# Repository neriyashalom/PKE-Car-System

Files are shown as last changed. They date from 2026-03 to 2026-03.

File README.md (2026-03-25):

# PKE-Car-System

# ESP32-S3 Based PKE System for Vehicle Access and Ignition

## Project Overview
This project presents the design and implementation of a Passive Keyless Entry (PKE) system for a vehicle, based on the ESP32-S3 microcontroller.  
The system enables keyless door locking and unlocking, mirror folding and unfolding, and vehicle ignition control through a Start-Stop push button, using BLE proximity detection.

The project combines hardware, firmware, PCB design, and practical testing into a complete embedded automotive-oriented solution.  
A dedicated PCB was designed to integrate the ESP32-S3 controller, protection circuits, input conditioning stages, relay drivers, and relay blocks required for interfacing with the vehicle.

In addition to the PKE functionality, the system was designed to operate alongside the original vehicle key without interfering with its normal operation.

## System Architecture
The system is built around the following main blocks:

- ESP32-S3 controller
- BLE-based proximity detection
- Start-Stop push button interface
- Vehicle input conditioning circuits
- Protection and voltage level adaptation circuits
- Relay drivers and relay blocks
- Dedicated custom PCB
- Power management and DC-DC conversion

## Main Inputs
- BLE tag for proximity detection
- Brake pedal signal
- Handbrake signal
- Door status signal
- Ignition status signal
- Start-Stop button feedback

## Main Outputs
- Door lock control
- Door unlock control
- Mirror fold and unfold control
- ACC control
- IGN control
- START control
- Turn signal indication outputs
- Start-Stop button LED control

## Key Features
- Passive keyless vehicle access using BLE proximity detection
- Start-Stop ignition control based on defined safety conditions
- Support for vehicle functions such as mirrors, blinkers, and ignition lines
- Dedicated PCB for structured and reliable hardware integration
- State-based firmware logic for clear and predictable system behavior
- Practical implementation and testing on prototype and final PCB
- Compatibility with the original vehicle key system

## Repository Structure
- `Code/` - source code for the ESP32-S3 based PKE controller
- `KICAD/` - schematic and PCB design files created in KiCad
- `Multisim/` - simulation files used during the design and verification stages
- `ESP32S3.jpg` - image of the implemented ESP32-S3 based hardware
- `Final Project.pdf` - final project documentation and report
- `README.md` - general description of the project and repository contents

## Tools and Technologies
- **Microcontroller:** ESP32-S3
- **Firmware:** Arduino IDE, C/C++
- **PCB Design:** KiCad
- **Simulation:** Multisim
- **Communication:** BLE
- **Hardware:** Relay drivers, relays, protection circuits, DC-DC converter
- **Application Domain:** Embedded systems, automotive electronics

## Project Outcome
The project demonstrates a complete embedded hardware-software solution for implementing a custom PKE system in a vehicle environment.  
It includes concept definition, hardware design, PCB implementation, firmware development, simulation, prototype testing, and final integration.

## Author
Final project in Electrical and Electronics Engineering  
Developer: Neriya Shalom

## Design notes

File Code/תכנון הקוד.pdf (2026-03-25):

.1 דרישות תוכנה
.1.1 מטרת הפרק

פרק זה מגדיר את דרישות ההתנהגות של תוכנת הבקר עבור מערכת Entry Keyless Passive לרכב. המטרה היא לתאר בצורה ברורה את מצבי המערכת, תנאי ההפעלה, הפלטים, מגבלות הבטיחות ותרחישי הקצה, לפני תחילת כתיבת הקוד.

.1.2 הנחיות בסיסיות

- הקוד נועד לסביבת העבודה IDE Arduino.
- הקוד צריך להיות במבנה קלאסי ופשוט על ליבה אחת.
- ערכי RSSI סטנדרטיים ושינוי לפי ניסוי וטעיה.
.TARGET_MAC = "dc:0d:30:2b:84:8f" :כך | יוגדר | BLE
- סינון קלטים קטן של ms50 בנוסף לסינון החומרתי.
- טבלת הקצאת הפינים (שבשימוש) עבור הבקר ESP נמצאת בסוף המסמך.

הפרק נועד לשמש בסיס עבור:

- כתיבת לוגיקת התוכנה.
.State Machine | בניית |
- חלוקת הקוד למודולים.
- בדיקות ואימות המערכת.

.1.3 מטרת המערכת

המערכת מיועדת לאפשר:

- זיהוי משתמש באמצעות תג BLE.
- פתיחה ונעילה של הרכב.
- קיפול ופתיחת מראות.
- חיווי באמצעות וינקרים.
.ACC, IGN, START קווי | על | שליטה |
- שליטה באמצעות כפתור STOP/START חיצוני.
- עבודה במקביל למפתח המקורי של הרכב ללא התנגשות.

.1.4 קלטים למערכת

הבקר יקבל את הקלטים הבאים:

- זיהוי מפתח באמצעות BLE.
- עוצמת קליטה לצורך החלטת קרבה או התרחקות.
- SIG_BTN - פידבק מכפתור ההנעה.
- SIG_BRAKE - חיווי לחיצה על דוושת הבלם.
- SIG_HB - חיווי בלם יד משוך.
- SIG_DOOR - חיווי מצב דלתות.
- SIG_IGN - משוב מקו ההצתה לזיהוי שליטת מפתח מקורי.
- RST - איפוס חיצוני.

.1.5 פלטים מהמערכת

הבקר ישלוט בפלטים הבאים:

- LOCK - נעילת דלתות.
- UNLOCK - פתיחת דלתות.
- ACC - קו חשמל אביזרים (תאורה, רדיו).
- IGN - קו הצתה.
- START - קו התנעה.
- BLINK_R - איתות (וינקר) ימין.
- BLINK_L - איתות (וינקר) שמאל.
. | מראות | קיפול | - MIRROR_CLOSE
. | מראות | פתיחת | - MIRROR_OPEN
- LED_BTN - תאורת לד כפתור ההתנעה.

.1.6 מצבים ראשיים של המערכת

המערכת תפעל לפי המצבים העיקריים הבאים:

- IDLE - מצב אתחול ומעבר ראשוני של המערכת. הבהרה: IDLE הוא מצב אתחול ומעבר רגעי בלבד. לאחר אתחול או RST המערכת מאפסת את כל הפלטים למצב בטוח , ולאחר מכן קובעת את מצב הרכב לפי מצב ה-BLE בזמן האתחול. אם אין מפתח מזוהה, המערכת תעבור ל-LOCKED ללא הפעלת רצף נעילה נוסף. אם יש מפתח מזוהה, המערכת תבצע רצף פתיחה מלא הכולל OPEN_MIRROR ,UNLOCK ו3- הבהובי איתות, ולאחר מכן תעבור ל-IDLE .UNLOCKED אינו מצב עבודה רגיל של רכב כבוי.
- LOCKED - רכב נעול וממתין לזיהוי מפתח.

- UNLOCKED - רכב פתוח ומוכן לפעולת משתמש.
- ON_ACC - מצב אביזרים פעיל.
- ON_IGN - מצב הצתה פעיל ללא התנעה.
- CRANKING - מצב הפעלת סטרטר.
- RUNNING_ENGINE - מצב מנוע פועל.
- ACTIVE_KEY_ORIGINAL - שליטה ע"י המפתח המקורי של הרכב.

.1.7 דרישות פונקציונליות (Requirement Functional (

זיהוי קרבה:

-01FR: המערכת תזהה נוכחות משתמש באמצעות BLE.

-02FR: שינוי בין מצב "קרוב" ל"רחוק" יתבצע רק לאחר סינון תנודות בעוצמת הקליטה, כדי למנוע פתיחה או נעילה שגויה.

-03FR: שינוי מצב כתוצאה מ-RSSI יתבצע רק לאחר מעבר סף ולמשך זמן סינון שיוגדר.

פתיחה, נעילה, איתותים ומראות:

-04FR: בעת פתיחת הרכב תופעל פעולת פתיחה למשך 0.5 שנייה.

-05FR: בעת נעילת הרכב תופעל פעולת נעילה למשך 0.5 שנייה.

-06FR: בעת פתיחת הרכב יופעל חיווי וינקרים של 3 הבהובים מהירים, כאשר כל הבהוב כולל 0.333 שנייה דולק ו0.333- שנייה כבוי.

-07FR: בעת נעילת הרכב יופעל חיווי וינקרים רציף למשך 3 שניות.

-08FR: בעת פתיחת מראות יופעל פולס של 3 שניות על OPEN_MIRROR.

-09FR: בעת קיפול מראות יופעל פולס של 3 שניות על CLOSE_MIRROR.

-10FR: אם נעילה נכשלה עקב דלת פתוחה, המערכת תזהה את הכישלון מ-SIG_DOOR, תבצע פולס LOCK ולאחריו פולס UNLOCK לפי מסגרת הזמנים שהוגדרה, כדי לספק חיווי מכני לכך שהרכב לא ננעל. במקרה זה המראות לא יתקפלו כלל.

-11FR: במקרה של כישלון נעילה עקב דלת פתוחה, המערכת תפעיל 5 הבהובים מהירים בווינקרים כהתראת שגיאה כאשר כל הבהוב כולל 0.333 שנייה דולק ו0.333- שנייה כבוי.

-12FR: במקרה של כישלון נעילה, המערכת לא תאפשר התנגשות בין רצף פעיל לבין תנאי קלט חדשים, אלא תפעל לפי כללי קדימות מוגדרים. אם חל שינוי בתנאים בזמן שרצף כישלון הנעילה עדיין פעיל, הבקר יבטל את הרצף הפעיל ויעבור מיד לפעולה החדשה המתאימה. בפרט:
- אם הדלת נסגרת בזמן שה-BLE עדיין רחוק, רצף כישלון הנעילה יבוטל ותבוצע נעילה רגילה.
- אם המפתח חוזר להיות קרוב בזמן שהרצף עדיין פעיל, רצף כישלון הנעילה יבוטל ותישלח פעולת UNLOCK ליישור פיזי, והמערכת תישאר במצב UNLOCKED.
- אם לא חל שינוי בתנאים כל עוד רצף כישלון הנעילה פעיל, הבקר ישלים את שלבי הרצף הפעילים, כלומר פולס LOCK ולאחריו פולס UNLOCK, ולאחר מכן יחזור לקבל החלטות לפי מצב BLE והדלת בלולאה הראשית.

שליטת מפתח מקורי:

-13FR: אם מתקבל SIG_IGN כאשר הבקר עצמו לא הפעיל את קו IGN, המערכת תעבור למצב ACTIVE_KEY_ORIGINAL. בעת כניסה ל-ACTIVE_KEY_ORIGINAL, המערכת תבטל מיידית כל רצף PKE פעיל כולל פולסי UNLOCK/LOCK, פולסי מראות ואיתותי וינקרים.

-14FR: במצב ACTIVE_KEY_ORIGINAL הבקר יזהה שהשליטה בהנעה ובמצבי הסוויץ' מתבצעת על ידי המפתח המקורי, ולכן יעבור למצב שבו אינו מנהל את ההנעה. במצב זה הבקר יתעלם מכל פעולה שקשורה לכפתור ההנעה עד ליציאה ממצב זה, כלומר, לא יבצע פעולות START ,IGN ,ACC או כיבוי מנוע מטעמו ויכבה מיד את LED_BTN. אם בעת הכניסה למצב זה קיים הבהוב פעיל, בין אם הבהוב רגיל ובין אם הבהוב שגיאה, הכיבוי יתבצע לאחר סיום ההבהוב.

LOW | ונשאר | LOW-ל | יורד IGN_SIG | כאשר | תתבצע | ORIGINAL_KEY_ACTIVE | ממצב | היציאה | :FR-15
למשך זמן סינון קצר שיוגדר. לאחר יציאה מ-ACTIVE_KEY_ORIGINAL, הבקר לא יבצע פעולה פיזית מיידית על מנעולים, מראות או וינקרים, אלא יחזור למצב עבודה רגיל של PKE בלבד.
- BLE קרוב: המערכת תעבור ל-UNLOCKED ללא שליחת UNLOCK - ללא פתיחת מראות ואיתותים.
- BLE לא קרוב: המערכת תעבור ל-LOCKED ללא שליחת LOCK - ללא קיפול מראות ואיתותים. מכאן ואילך, כל פעולה פיזית תתבצע רק לפי לוגיקת ה-PKE הרגילה:
- BLE קרוב ובהמשך יתרחק - תתבצע נעילה רגילה או רצף כישלון נעילה לפי מצב הדלת.
- אם אין BLE בעת היציאה - לא תתבצע פעולה פיזית מיידית, מתוך הנחה שהמשתמש עשוי לעבוד רק עם המפתח המקורי ולנעול את הרכב באמצעותו.

רצף התנעה:

-16FR: התנעה תתאפשר רק כאשר המפתח מזוהה, הברקס לחוץ ובלם היד משוך.

-17FR: רצף ההתנעה בלחיצה אחת, כאשר תנאי ההתנעה מתקיימים במלואם, יהיה: הפעלת ACC ו-IGN, השהייה קצרה של שנייה אחת לצורך ייצוב המערכת ובניית לחץ דלק, ניתוק זמני של ACC, הפעלת START, ולאחר סיום START החזרת ACC.

-18FR: ההשהיה של שנייה אחת לפני START נדרשת בכל מסלול התנעה, כולל מעבר ממצב כבוי, מ-.IGN_ON-ומ ACC_ON

-19FR: מכיוון שאין במערכת משוב סל"ד (RPM(, הפעלת START תהיה מבוססת זמן. לחיצה בודדת בתנאי התנעה תקינים תפעיל את הסטרטר למשך 1.5 שניות, ולאחר מכן תנתק אותו אוטומטית.

-20FR: אם בלם היד אינו משוך, לא תתאפשר התנעה כלל, אך ACC ו -IGN עדיין יוכלו לעבוד לפי לוגיקת הכפתור.

-21FR: אם המפתח נעלם לאחר שהרכב כבר הונע, המנוע ימשיך לפעול עד לכיבוי יזום דרך הכפתור.

כפתור ההנעה וה-LED:

-22FR: ה-LED דולק ברציפות כאשר המפתח מזוהה והברקס לחוץ, או כאשר המערכת נמצאת במצב
. | הכפתור | לוגיקת | לפי ENGINE_RUNNING או ACC_ON, IGN_ON, CRANKING

-23FR: לאחר כיבוי מנוע ה-LED יכבה מיד, וגם אם הברקס עדיין לחוץ הוא יידלק מחדש רק בעקבות זיהוי מחודש של תנאי ההפעלה או לחיצה חדשה על הכפתור לפי לוגיקת המערכת.

-24FR: אם יש מפתח, בלם יד משוך וברקס לחוץ, לחיצה בודדת תגרום להתנעה. ה-LED יישאר דולק מרגע לחיצת הברקס עם הבהוב קצר לפידבק בעת הלחיצה.

-25FR: אם יש מפתח, בלם יד משוך וברקס לא לחוץ:

- לחיצה ראשונה תעביר למצב ON_ACC וה-LED יידלק.
- לחיצה שנייה תעביר למצב ON_IGN וה-LED יישאר דולק.
- לחיצה שלישית ללא ברקס, תכבה את ה-LED, תכבה ACC ו-IGN ותחזיר את המערכת ל-UNLOCKED) רכב פתוח וכבוי). אם נלחץ ברקס לפני הלחיצה השלישית, הלחיצה הבאה תגרום להתנעה.
-26FR: בכל לחיצה תקינה יתקבל הבהוב קצר של ה-LED כפידבק, מלבד לחיצה תקינה לכיבוי מנוע, שבה ה-LED עובר ממצב דולק למצב כבוי, ומעבר זה ייחשב כפידבק תקין ומספיק.

-27FR: אם אין מפתח וברקס לחוץ, ללא קשר למצב בלם היד, ה-LED יידלק בעת לחיצת הברקס. לחיצה בודדת על הכפתור תגרום ל- 4 הבהובים מהירים לציון שגיאה, ולאחר מכן ה-LED יחזור להיות דולק כל עוד הברקס לחוץ.

-28FR: אם אין מפתח וברקס לא לחוץ, ללא קשר למצב בלם היד, ה-LED יהיה כבוי, ולחיצה על הכפתור תגרום ל4- הבהובים מהירים ולאחר מכן תחזור למצב כבוי. דרישות -27FR ו-28-FR מתייחסות לכל מצב כבוי שבו אין מפתח מזוהה, כלומר כאשר המערכת אינה ב-.ENGINE_RUNNING או ACC_ON, IGN_ON

-29FR: שליטת ה-LED תתבצע דרך LED_BTN והאדמה הנשלטת על ידי 1Q.

-30FR: פידבק מהכפתור ייקרא דרך SIG_BTN.

כיבוי:

-31FR: כיבוי מנוע פועל יתאפשר רק כאשר הברקס לחוץ וגם בלם היד משוך.

-32FR: כיבוי ממצב ON_ACC או ON_IGN כאשר המנוע אינו פועל, כלומר כאשר המערכת אינה במצב RUNNING_ENGINE, יתאפשר גם ללא לחיצה על הברקס. דרישה זו תקפה גם אם המפתח היה מזוהה בעת הכניסה ל-ON_ACC או ON_IGN ולאחר מכן אבד. במקרה כזה, הלחיצה הבאה על הכפתור ממצב ON_ACC או ON_IGN תבצע כיבוי של הקווים הפעילים ותחזיר את המערכת ל-UNLOCKED, עם הבהוב קצר רגיל של ה-LED כפידבק ללחיצה תקינה ו ללא חיווי שגיאה.

-33FR: כיבוי חירום יתאפשר באמצעות לחיצה רצופה של 5 שניות על כפתור ההנעה, ללא תלות בתנאי הברקס או בלם היד.

-34FR: כאשר המנוע פועל, לחיצה קצרה על כפתור ההנעה תבצע כיבוי רק אם הברקס לחוץ וגם בלם היד משוך. אם מתקיים רק אחד התנאים, או אם אף אחד מהם אינו מתקיים, הלחיצה תתעלם ולא תבצע פעולה.

הגנה מפריקת מצבר:

-35FR: אם המערכת במצב ON_ACC או ON_IGN, המנוע אינו פועל והמפתח אינו מזוהה, המערכת תכבה אוטומטית את הקווים האלה לאחר 5 דקות.

איפוס חיצוני:

-36FR: איפוס דרך RST באמצעות כפתור חיצוני יגרום להפעלה מחדש מיידית של הבקר.

-37FR: לאחר איפוס, המערכת תחזור למצב רגיל של אתחול, קריאת מצב ה-BLE וקבלת החלטה בהתאם לנוכחות המפתח. אם בעת סיום האתחול אין מפתח מזוהה, המערכת תעבור ל-LOCKED ללא הפעלת רצף נעילה נוסף. אם בעת סיום האתחול יש מפתח מזוהה, המערכת תבצע רצף פתיחה מלא הכולל ,UNLOCK OPEN_MIRROR ו3- הבהובי איתות, ולאחר מכן תעבור ל-UNLOCKED.

.1.8 דרישות בטיחות (Requirements Safety (

-01SR: אין לאפשר התנעה ללא מפתח מזוהה.

-02SR: אין לאפשר התנעה ללא ברקס לחוץ.

-03SR: אין לאפשר התנעה ללא בלם יד משוך.

-04SR: אין לאפשר נעילה אוטומטית סופית כאשר דלת פתוחה. במקרה זה מותר לבצע רק רצף כישלון נעילה, הכולל פולס LOCK קצר ולאחריו פולס UNLOCK.

-05SR: אין לאפשר כיבוי מנוע פועל ללא ברקס לחוץ ובלם יד משוך, מלבד כיבוי חירום.

-06SR: אובדן מפתח לאחר התנעה לא יגרום לכיבוי המנוע.

-07SR: במצב ACTIVE_KEY_ORIGINAL הבקר לא ינסה להשתלט על IGN ,ACC או START.

-08SR: לאחר אתחול או איפוס, כל הפלטים יחזרו למצב בטוח כברירת מחדל.

-09SR: קווי LOCK ו-UNLOCK יופעלו כפולסים קצרים בלבד לפי הזמנים שהוגדרו.

-10SR: פולסי מראות ופולסי וינקרים יופעלו רק לפי הזמנים שהוגדרו ולא ברציפות בלתי מבוקרת.

או ACC_ON, IGN_ON, CRANKING, ENGINE_RUNNING | במצב | נמצאת | המערכת | כאשר | :SR-11
ACTIVE_KEY_ORIGINAL, מנגנון ה-PKE האוטומטי, כלומר נעילה או פתיחה מבוססת קרבה וקיפול מראות, מנוטרל לחלוטין. לא תתבצע שום פעולת מראות או מנעולים כתוצאה משינויי קליטה (RSSI (עד שהרכב יחזור למצב כבוי, כלומר LOCKED או UNLOCKED, כאשר אף קו START/IGN/ACC אינו פעיל.

-12SR: המערכת לא תפעיל במקביל פלטים או רצפים סותרים. בפרט, לא יופעלו יחד LOCK ו-UNLOCK, לא יופעלו יחד OPEN_MIRROR ו-CLOSE_MIRROR, ולא ירוץ רצף PKE אוטומטי במקביל לאירוע בעל קדימות גבוהה כגון כניסה ל-ACTIVE_KEY_ORIGINAL. במקרה של שינוי תנאים באמצע רצף פעיל, הבקר יבטל או יסיים את הרצף לפי כללי הקדימות שהוגדרו בדרישות הפונקציונליות.

.1.9 תרחישי קצה שיש לכסות

הקוד חייב להתחשב לפחות בתרחישים הבאים:

.1 לחיצה על כפתור ללא מפתח. .2 לחיצה על כפתור עם מפתח אך ללא ברקס. .3 ניסיון התנעה ללא בלם יד. .4 ניסיון נעילה כאשר דלת פתוחה. .5 אובדן מפתח לאחר התנעה.
.6 כיבוי חירום בלחיצה ארוכה.

.7 איפוס בזמן שהמערכת ב-IGN ,ACC או RUNNING_ENGINE. .8 שליטת מפתח מקורי דרך SIG_IGN. .9 מעבר חזרה מ-ACTIVE_KEY_ORIGINAL למצב רגיל. .10 תנודות RSSI הגורמות לזיהוי קרבה לא יציב. .11 ניסיון כיבוי מנוע פועל ללא ברקס ובלם יד. .12 כישלון נעילה והפעלת פתיחה מחדש. .13 מעבר מהיר ממצב כבוי להתנעה בלחיצה אחת תוך התחשבות בהשהייה של שנייה אחת לפני START. .14 התנעה לאחר שהמשתמש כבר העלה את המערכת ל-IGN בלחיצות קודמות, גם במעבר מ-ON_IGN ישירות להתנעה, השהיית DELAY_START_PRE תמיד מתקיימת, ואין מסלול התנעה ללא השהיה . .15 שחרור ברקס באמצע ניסיון התנעה. .16 שינוי תנאים באמצע רצף כישלון נעילה:
- אם הדלת נסגרת בזמן שרצף כישלון הנעילה עדיין פעיל וה-BLE עדיין רחוק, המערכת תבטל את הרצף הפעיל ותבצע נעילה רגילה מיד.
- אם המפתח חוזר להיות קרוב בזמן שרצף כישלון הנעילה עדיין פעיל, המערכת תבטל את הרצף הפעיל, תשלח UNLOCK ליישור פיזי, ותישאר במצב UNLOCKED.

.1.10 ערכי זמן קבועים

המערכת תתבסס על הערכים הבאים:

LOCK_PULSE = 0.5s
זמן הפעלת פלט הנעילה.
UNLOCK_PULSE = 0.5s
זמן הפעלת פלט הפתיחה.
LOCK_BLINK_DURATION = 3s זמן הפעלת שני צדדי הווינקר בנעילה. UNLOCK_BLINK_COUNT = 3
בפתיחה שני צדדי הווינקר יבוצעו 3 הבהובים. UNLOCK_BLINK_ON_TIME = 0.333s משך הזמן שבו הווינקרים דולקים בכל הבהוב פתיחה. UNLOCK_BLINK_OFF_TIME = 0.333s משך הזמן שבו הווינקרים כבויים בין הבהובי הפתיחה. LOCK_FAIL_BLINK_COUNT = 5 במקרה של כישלון נעילה יבוצעו 5 הבהובים של הווינקרים. LOCK_FAIL_BLINK_ON_TIME = 0.333s משך הזמן שבו הווינקרים דולקים בכל הבהוב של כישלון נעילה. LOCK_FAIL_BLINK_OFF_TIME = 0.333s משך הזמן שבו הווינקרים כבויים בין הבהובי כישלון הנעילה. LED_BLINK_ON_TIME = 0.333s משך הזמן שבו הלד דולק בכל הבהוב של מעבר מצב בלחיצות.

LED_BLINK_OFF_TIME = 0.333s משך הזמן שבו הלד כבוי בכל הבהוב של מעבר מצב בלחיצות. LED_ERROR_BLINK_COUNT = 4 במקרה של שגיאה או פקודת התנעה לא חוקית יבוצעו 4 הבהובים של הלד. LED_ERROR_BLINK_ON_TIME = 0.333s משך הזמן שבו הלד דולק בכל הבהוב של שגיאה או פקודת התנעה לא חוקית. LED_ERROR_BLINK_OFF_TIME = 0.333s משך הזמן שבו הלד כבוי בין הבהובי שגיאה או פקודת התנעה לא חוקית. MIRROR_OPEN_PULSE = 3s
זמן הפעלת פלט פתיחת המראות. MIRROR_CLOSE_PULSE = 3s
זמן הפעלת פלט קיפול המראות. PRE_START_DELAY = 1s
השהיה לייצוב המערכת ובניית לחץ דלק לפני הפעלת הסטרטר. START_PULSE = 1.5s
זמן הפעלת הסטרטר.
EMERGENCY_STOP_PRESS = 5s משך לחיצה רצופה על כפתור ההנעה לצורך כיבוי חירום. ACC_IGN_AUTO_OFF_TIMEOUT = 5min זמן מקסימלי למצב ACC או IGN ללא מנוע פועל וללא מפתח מזוהה.

.1.11 מבנה תוכנה

התוכנה תחולק למודולים נפרדים:
- קריאת קלטים.
- סינון קלטים .
- BLE וזיהוי קרבה.
- טיימרים.
.State Machine
- לוגיקת כפתור ההנעה.
- לוגיקת התנעה וכיבוי.
- לוגיקת נעילה, פתיחה, מראות ואיתותים.
.ORIGINAL_KEY_ACTIVE | במצב | טיפול |
- טיפול בתקלות ובמצבי חסימה.

.1.12 דרישות תוכנה (Requirement Software (

-01SW: כל לוגיקת ההחלטה תתבצע דרך Machine State מסודר.

-02SW: כל קלט חיצוני יעבור סינון לפני שימוש בלוגיקה הראשית.

-03SW: כל פלט בזמן ריצת המערכת יופעל דרך פונקציה ייעודית אחת בלבד.

-04SW: ניהול רצפים אסינכרוניים יתבצע באמצעות דגלי מצב, טיימרים וכללי קדימות ברורים, כך שבכל רגע נתון לכל תחום פעולה יהיה רצף פעיל אחד בלבד.

-05SW: בעת שינוי תנאים במהלך רצף פעיל, ההחלטה אם לבטל את הרצף או לאפשר לו להסתיים תיקבע לפי כללי הקדימות שהוגדרו בדרישות הפונקציונליות והבטיחות.

הקצאת הפינים (שבשימוש) עבור הבקר ESP מפורטת בטבלה הבאה:

תיאור | I/O Type | GPIO | Signal Name
מוצא V3.3 המשמש כמתח יחוס לכניסות חיווי DOOR_NEG-ו HB_NEG | - 3V3 Power Output
(Reset) חומרתי איפוס לחצן | Input | EN | RST
| | | LOCK 4 Output מוצא לדרייבר ממסר נעילת דלתות הרכב
| | | UNLOCK 9 Output מוצא לדרייבר ממסר פתיחת דלתות הרכב
כניסת חיווי דוושת בלם (משוחרר/משוך) לאחר הגבלת מתח הכניסה | | | SIG_BRAKE 10 Input
| | | SIG_HB 11 Input כניסת חיווי בלם יד לאחר הגבלת מתח הכניסה
כניסת חיווי מצב דלתות הרכב (פתוחות/סגורות) לאחר הגבלת מתח הכניסה | | | SIG_DOOR 12 Input
כניסת חיווי מצב הצתה מהרכב ע"י מפתח מקורי לצורך השבתת המערכת לאחר הגבלת מתח הכניסה | Input | 13 | IGN_SIG
כניסת חיווי מכפתור ההנעה לאחר הגבלת מתח הכניסה | | | SIG_BTN 14 Input
| | | V+5 - Input Power כניסת מתח V5 מממיר המתח
| | | GND - Power חיבור אדמה משותף למרכב הרכב
| | | GND - Power חיבור אדמה משותף למרכב הרכב
| | | START 1 Output מוצא לדרייבר ממסר הפעלת הסטרטר (התנעה)
מוצא לדרייבר ממסר הפעלת מתח אביזרים (תאורה, מצת וכד') | | | ACC 2 Output
| | | IGN 42 Output מוצא לדרייבר ממסר הפעלת מערכת ההצתה
| | | CLOSE_MIRROR 41 Output מוצא לדרייבר ממסר סגירת מראות הצד
| | | OPEN_MIRROR 40 Output מוצא לדרייבר ממסר פתיחת מראות הצד
| | | BLINK_L 48 Output מוצא לדרייבר ממסר הפעלת איתות שמאלי
| | | BLINK_R 47 Output מוצא לדרייבר ממסר הפעלת איתות ימני
מוצא לדרייבר ממסר הפעלת תאורה בכפתור ההנעה | | | LED_BTN 21 Output
| | | GND - Power חיבור אדמה משותף למרכב הרכב
| | | GND - Power חיבור אדמה משותף למרכב הרכב

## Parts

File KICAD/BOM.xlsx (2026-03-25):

Reference | Footprint | Qty | Perfboard (ללוח הלחמה לבדיקה) | SMD (ללוח PCB מודפס)
C1,C3,C4,C5,C6,C7 | Capacitor_SMD:C_0805_2012Metric_Pad1.18x1.45mm_HandSolder | 6 | 100n THT | Capacitor 100nF 50V X7R 0805
C2 | Capacitor_THT:CP_Radial_D8.0mm_P3.50mm | 1 | 50V220u THT | Electrolytic Capacitor 220uF 50V Radial_D8.0mm_P3.50mm
D1 | Diode_SMD:D_SMB_Handsoldering | 1 | SR560 THT | SS56 SMB
D2 | Diode_SMD:D_SMC_Handsoldering | 1 | P6KE18A THT | SMCJ18A SMC
D3,D5,D6,D7,D8 | Diode_SMD:D_SOD-123 | 5 | 1N4728A THT | BZT52C3V3 SOD-123
D4,D9,D10,D11,D12,D13,D14,D15,D16,D17 | Diode_SMD:D_SMA_Handsoldering | 10 | 1N4007 THT | 1N4007 SMA
ESP32_S3_DevKitC_1 | ESP32-S3-DevKitC-1-N32R16V:ESP32S3DevKitC1N32R16V | 1 | ESP32_S3_DevKitC THT | ESP32_S3_DevKitC THT
F1 | Fuse:Fuse_1812_4532Metric_Pad1.30x3.40mm_HandSolder | 1 | FUSE_DCDC 1.1A THT | 1812 4.8*3.2mm
F2 | Fuse:Fuse_1812_4532Metric_Pad1.30x3.40mm_HandSolder | 1 | FUSE_COILS 1.1A THT | 1812 4.8*3.2mm
J1,J3 | Connector_Molex:Molex_Mini-Fit_Jr_5569-06A2_2x03_P4.20mm_Horizontal | 2 | Molex_Mini-Fit_Jr_5569-06A2_2x03 THT | Molex_Mini-Fit_Jr_5569-06A2_2x03 THT
J2 | Connector_Molex:Molex_Mini-Fit_Jr_5569-16A2_2x08_P4.20mm_Horizontal | 1 | Molex_Mini-Fit_Jr_5569-16A2_2x08 THT | Molex_Mini-Fit_Jr_5569-16A2_2x08 THT
J_DCDC1 | Connector_PinHeader_2.54mm:PinHeader_1x03_P2.54mm_Vertical | 1 | 3 Holes for external module THT | 3 Holes for external module THT
J_RST1 | Connector_PinHeader_2.54mm:PinHeader_1x02_P2.54mm_Horizontal | 1 | 2 Holes for external module THT | 2 Holes for external module THT
K1,K2,K3,K4,K5,K6,K7,K8,K9 | CMA51H_RELAY:CMA51HSDC12VC | 9 | CMA51H-S-DC12V-C THT | CMA51H-S-DC12V-C THT
Q1,Q2,Q3,Q4,Q5,Q6,Q7,Q8,Q9,Q10 | Package_TO_SOT_SMD:SOT-23-3 | 10 | 2N2222A THT | MMBT2222A SOT-23-3
R1,R2,R7,R10,R13,R16,R18,R19,R20,R24,R25,R28,R29,R32,R33 | Resistor_SMD:R_0805_2012Metric_Pad1.20x1.40mm_HandSolder | 15 | 1k THT | Resistor 1k 0805
R3,R6,R15 | Resistor_SMD:R_0805_2012Metric_Pad1.20x1.40mm_HandSolder | 3 | 30k THT | Resistor 30k 0805
R4,R21,R22,R23,R26,R27,R30,R31,R34,R35 | Resistor_SMD:R_0805_2012Metric_Pad1.20x1.40mm_HandSolder | 10 | 100k THT | Resistor 100k 0805
R5,R8,R17 | Resistor_SMD:R_0805_2012Metric_Pad1.20x1.40mm_HandSolder | 3 | 10k THT | Resistor 10k 0805
R9,R12 | Resistor_SMD:R_0805_2012Metric_Pad1.20x1.40mm_HandSolder | 2 | 4.7k THT | Resistor 4.7k 0805
R11,R14 | Resistor_SMD:R_0805_2012Metric_Pad1.20x1.40mm_HandSolder | 2 | 47k THT | Resistor 47k 0805

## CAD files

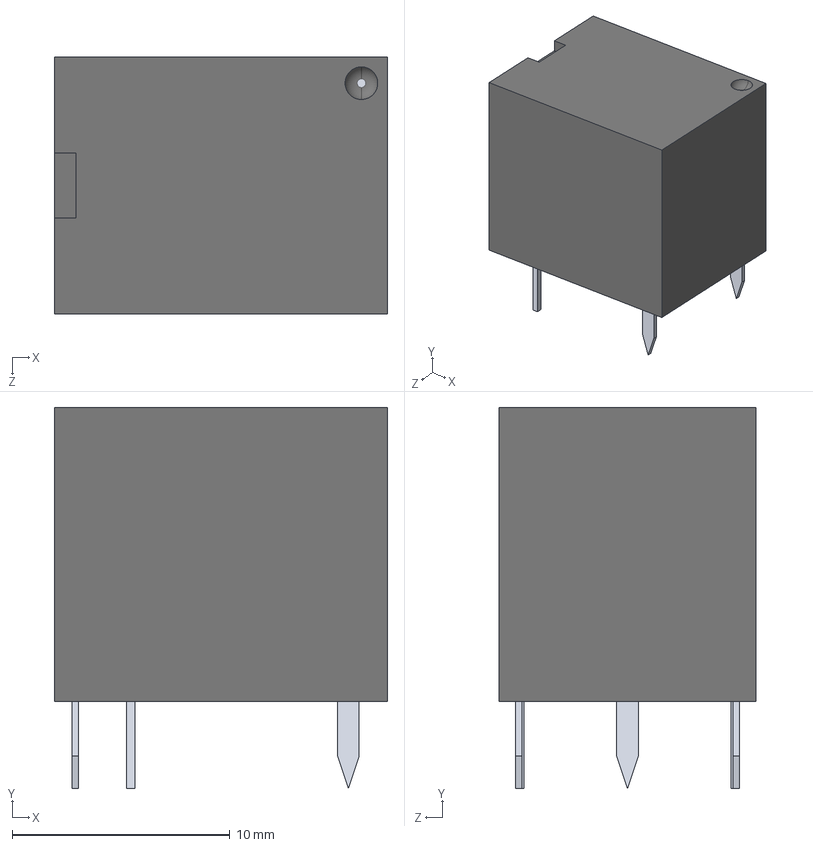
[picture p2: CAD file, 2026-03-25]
KICAD/CMA51H_RELAY/CMA51H-S_DC12V-C_20A.STEP
15.3 x 17.5 x 11.8 mm

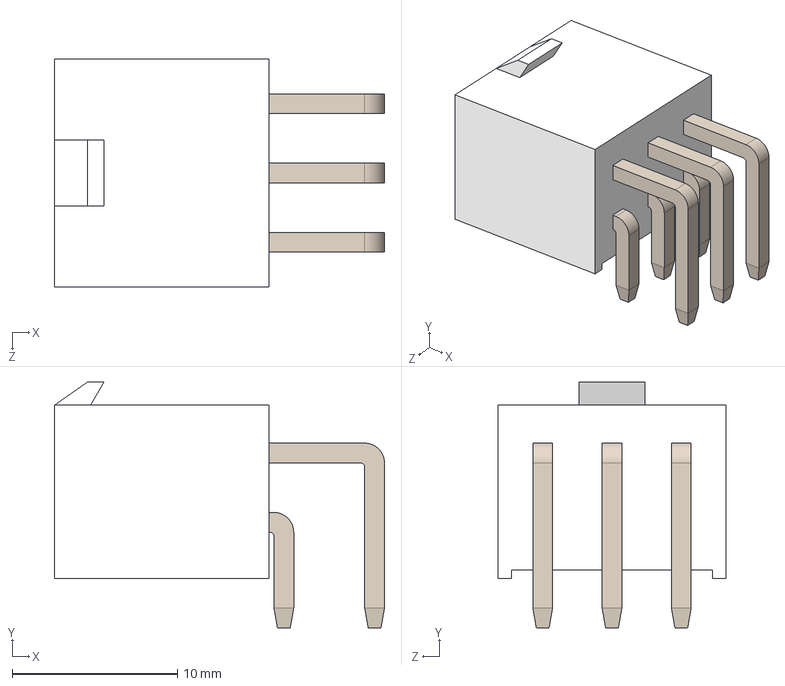
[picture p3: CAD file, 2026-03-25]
KICAD/Connectors/5557-2x1aw-5557-2x2aw-5557-2x3aw-5557-2x4aw-5557-2x5aw-1.snapshot.3/5557 2x3AW.STEP
20.0 x 14.9 x 13.8 mm

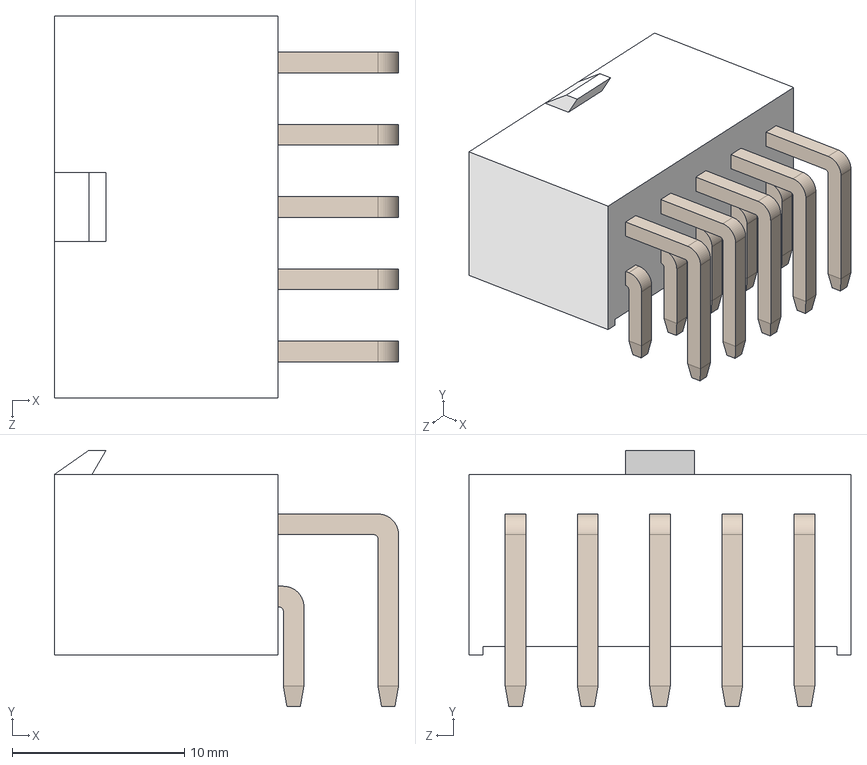
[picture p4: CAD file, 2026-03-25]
KICAD/Connectors/5557-2x1aw-5557-2x2aw-5557-2x3aw-5557-2x4aw-5557-2x5aw-1.snapshot.3/5557 2x5AW.STEP
20.0 x 14.9 x 22.2 mm

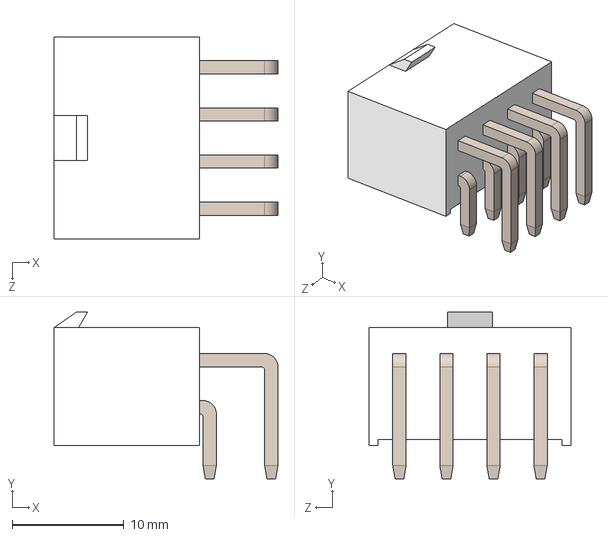
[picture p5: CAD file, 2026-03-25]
KICAD/Connectors/5557-2x1aw-5557-2x2aw-5557-2x3aw-5557-2x4aw-5557-2x5aw-1.snapshot.3/5557 2x4AW.STEP
20.0 x 14.9 x 18.0 mm

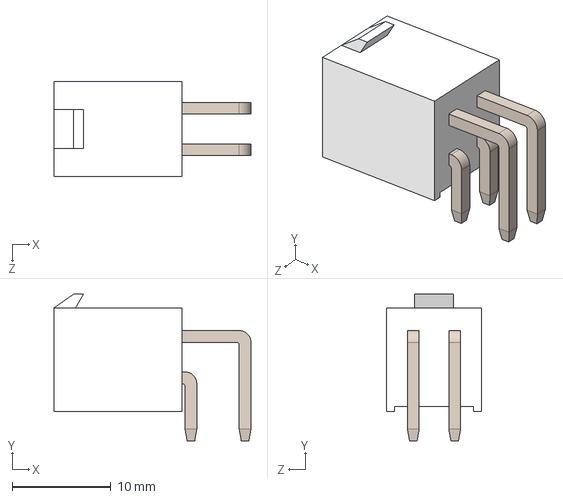
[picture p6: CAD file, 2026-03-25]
KICAD/Connectors/5557-2x1aw-5557-2x2aw-5557-2x3aw-5557-2x4aw-5557-2x5aw-1.snapshot.3/5557 2x2AW.STEP
20.0 x 14.9 x 9.60 mm

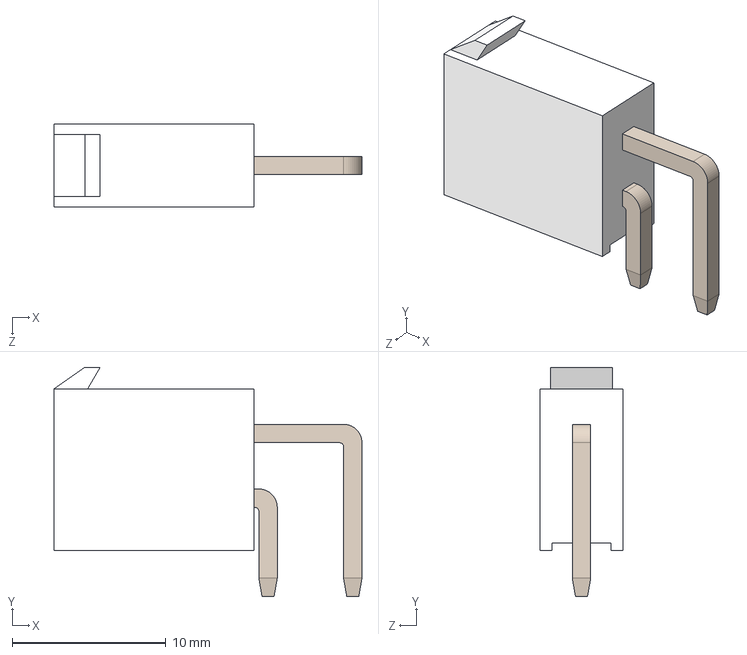
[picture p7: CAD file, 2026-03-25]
KICAD/Connectors/5557-2x1aw-5557-2x2aw-5557-2x3aw-5557-2x4aw-5557-2x5aw-1.snapshot.3/5557 2x1AW.STEP
20.0 x 14.9 x 5.40 mm

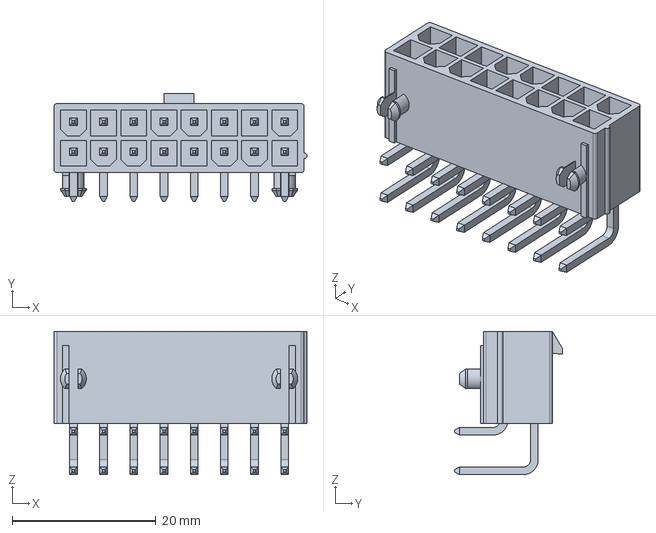
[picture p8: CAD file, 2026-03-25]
KICAD/Connectors/Molex_Mini-Fit_Jr_5569-16A2/0039301160.stp
35.2 x 15.0 x 19.9 mm

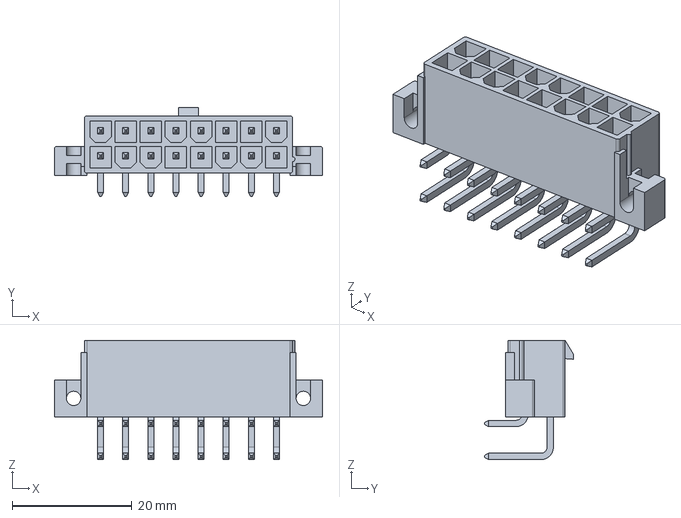
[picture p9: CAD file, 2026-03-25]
KICAD/Connectors/Molex_Mini-Fit_Jr_5569-16A2/0039291168.stp
44.8 x 14.9 x 19.9 mm

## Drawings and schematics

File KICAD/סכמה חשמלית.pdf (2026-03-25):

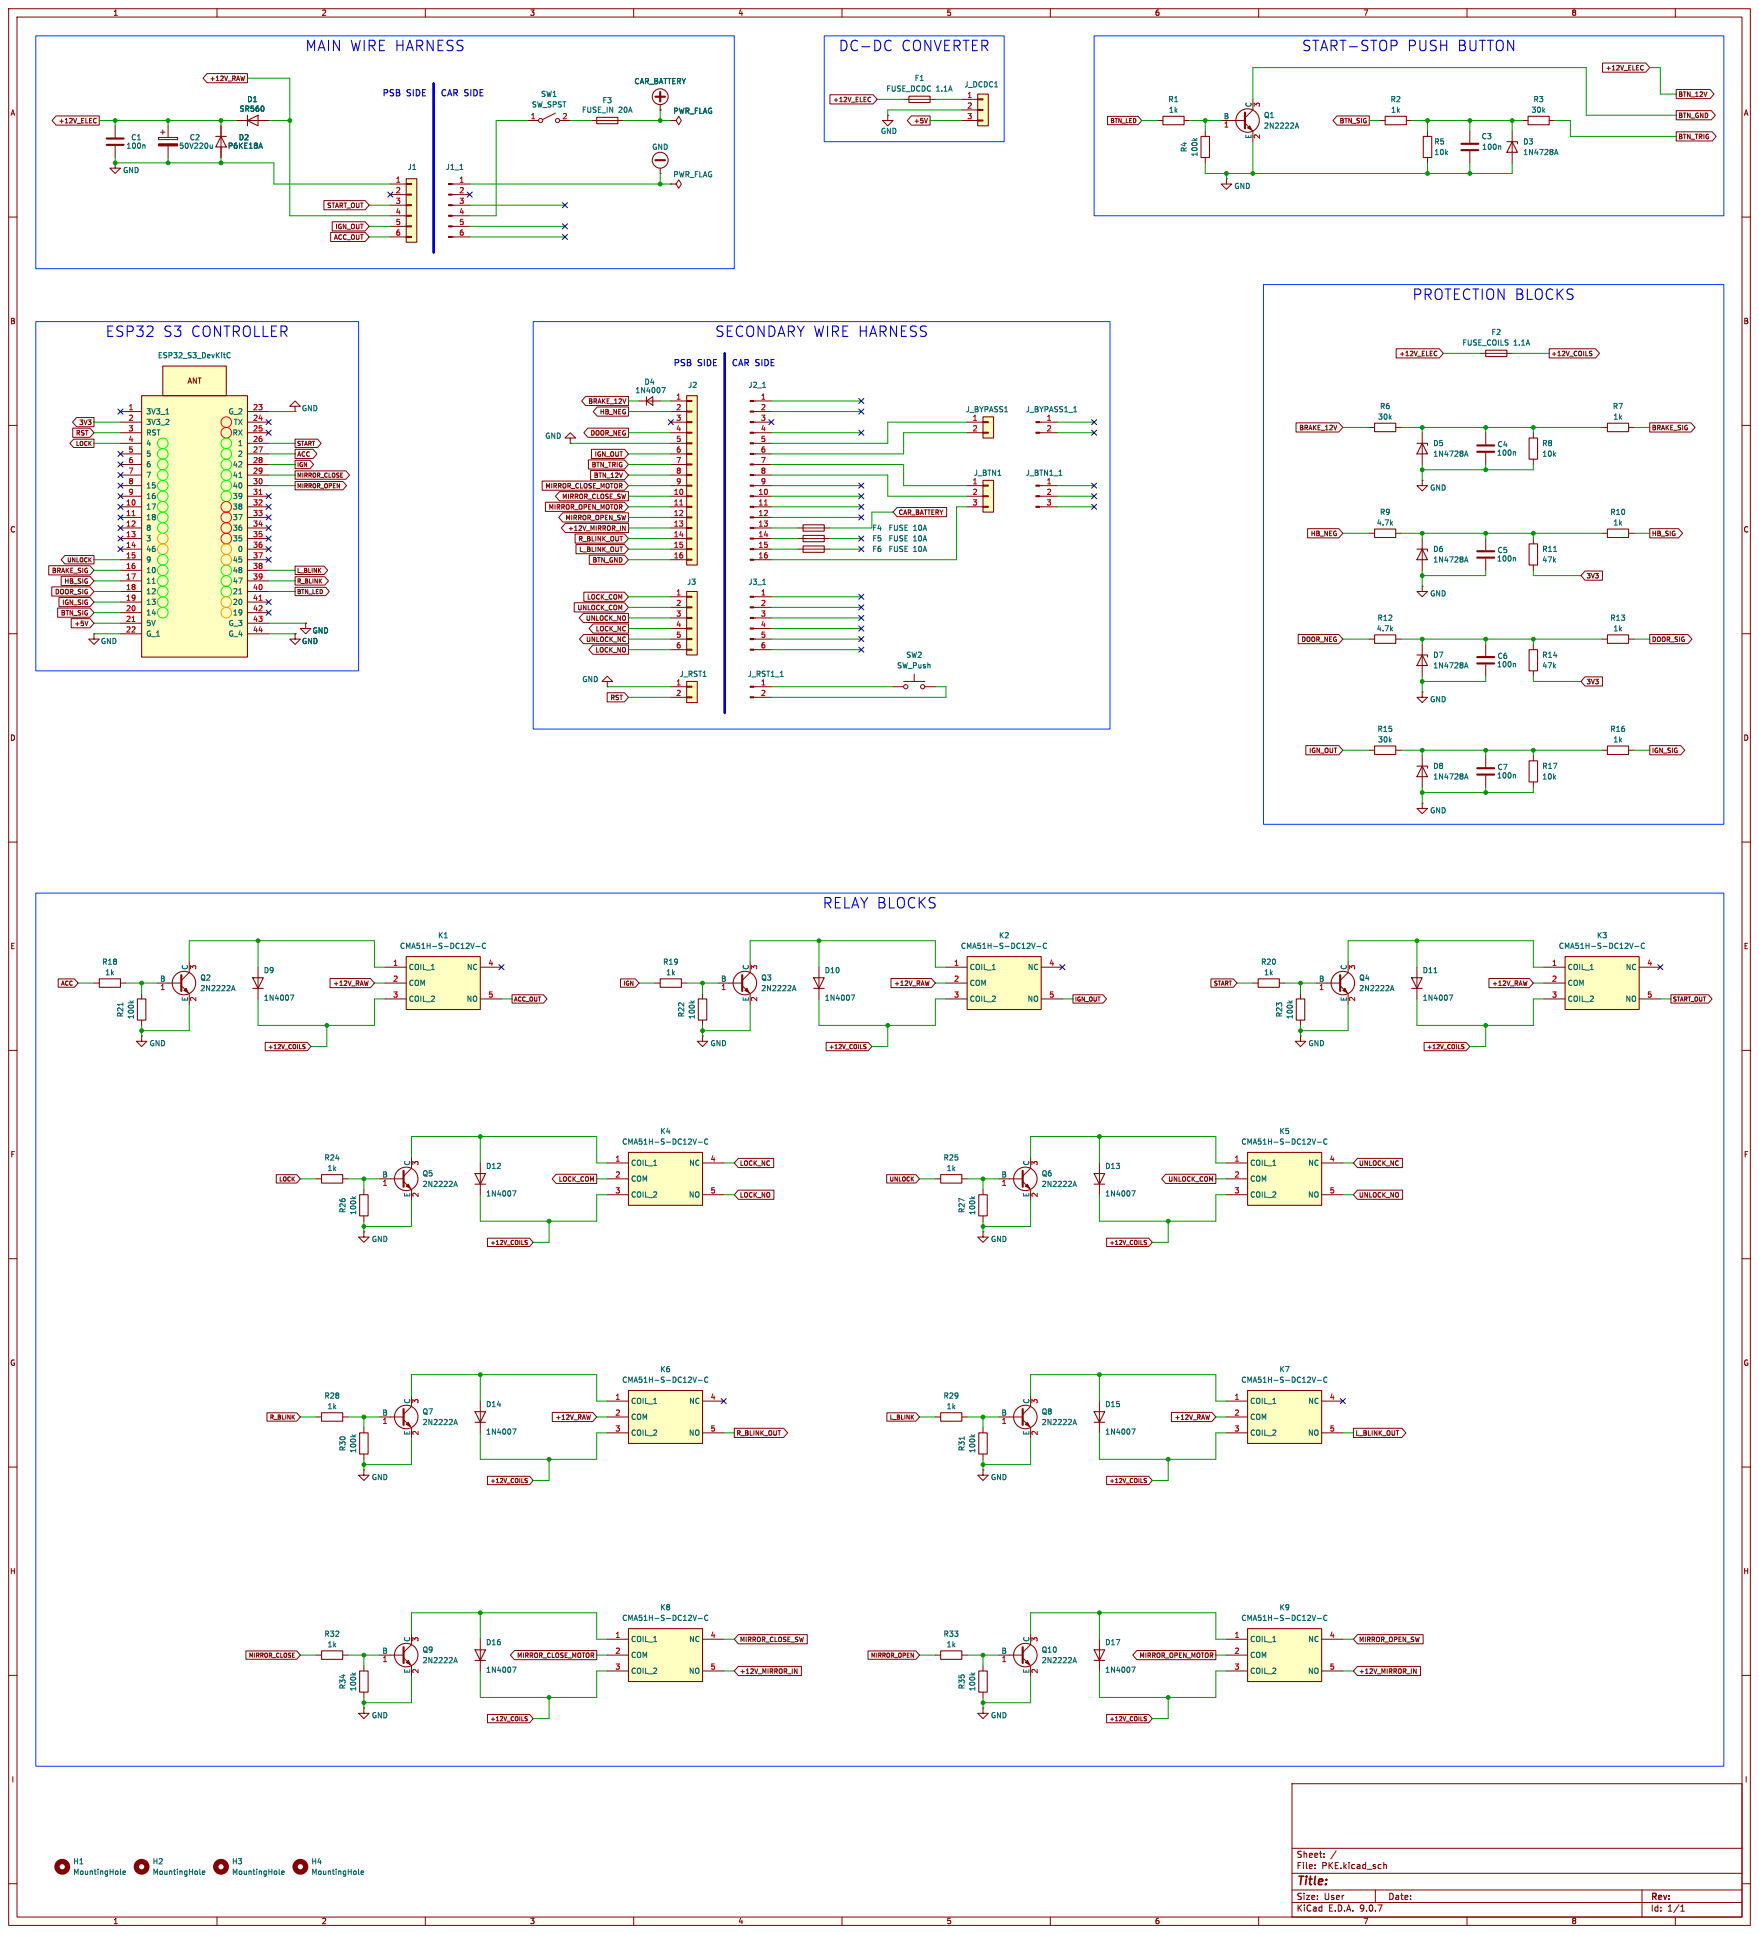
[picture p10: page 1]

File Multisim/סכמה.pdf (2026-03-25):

## D(freq): --

## D(freq): --

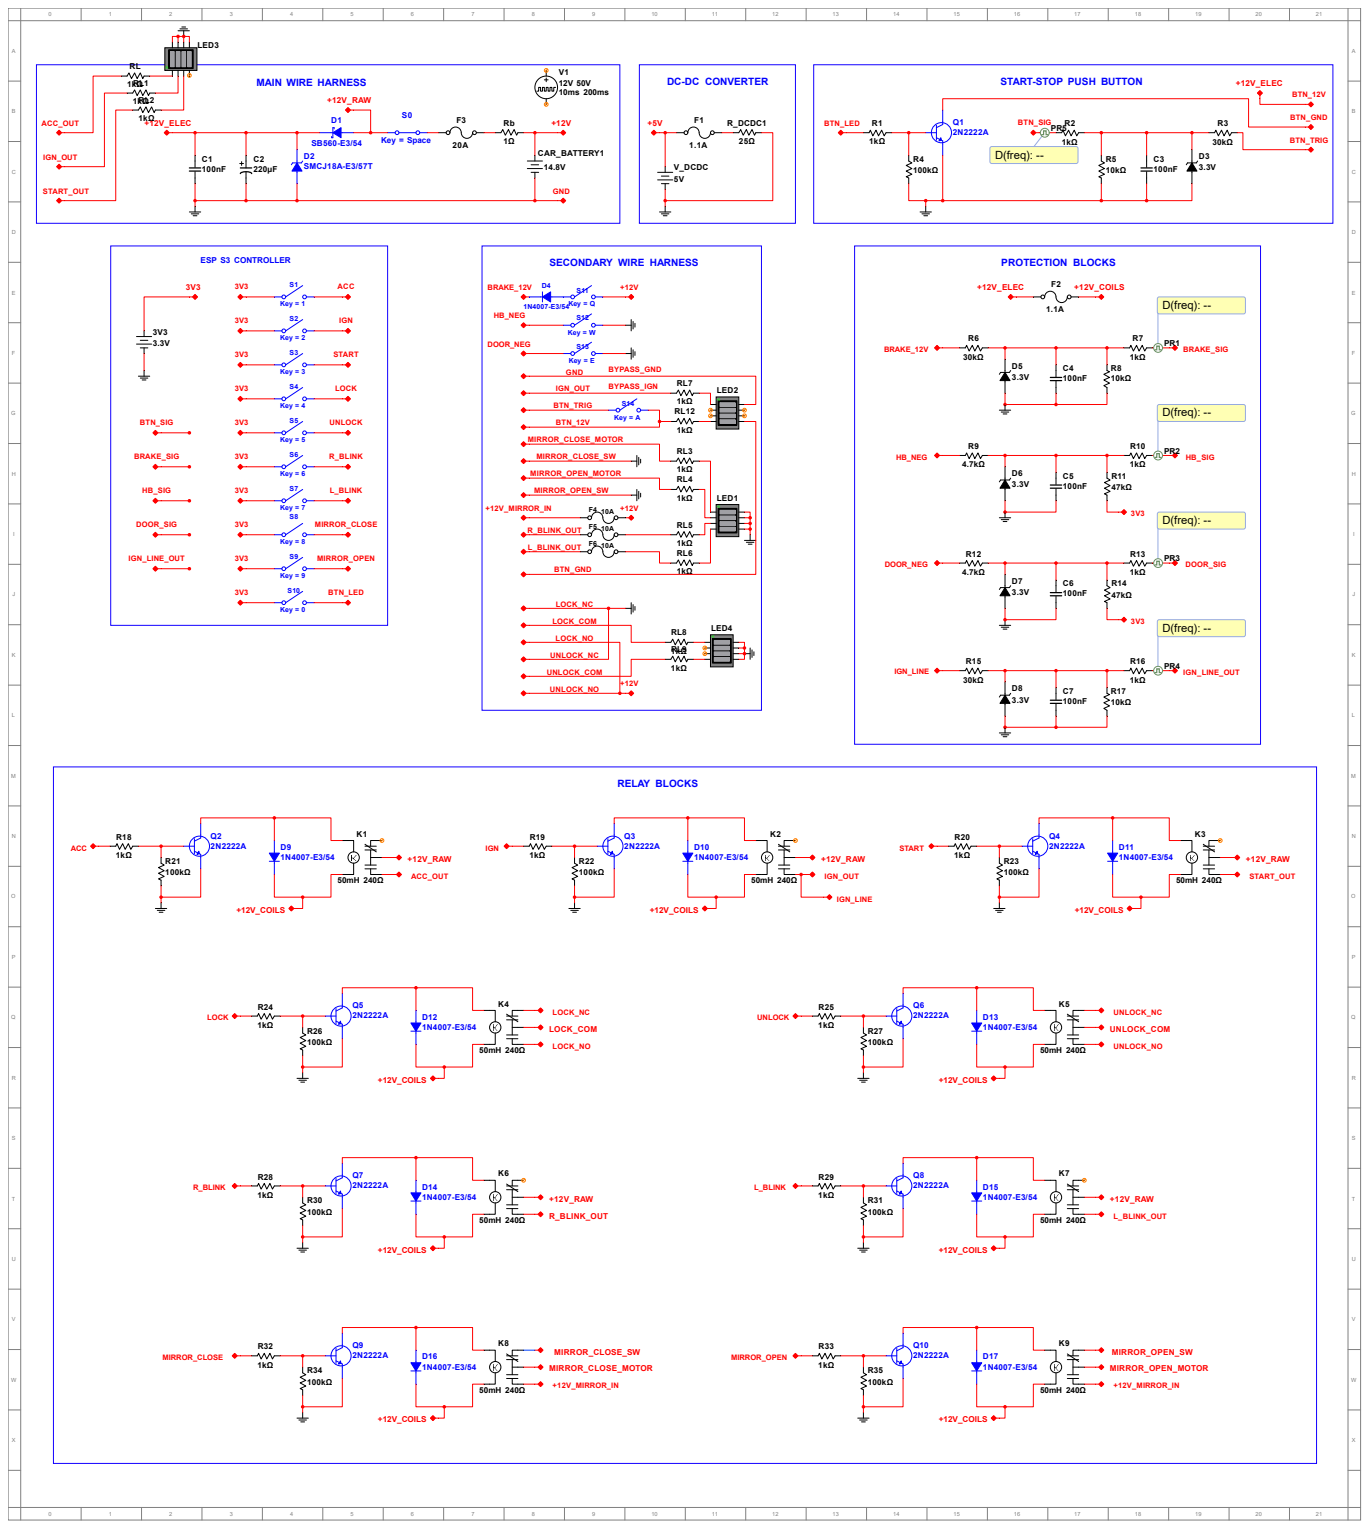
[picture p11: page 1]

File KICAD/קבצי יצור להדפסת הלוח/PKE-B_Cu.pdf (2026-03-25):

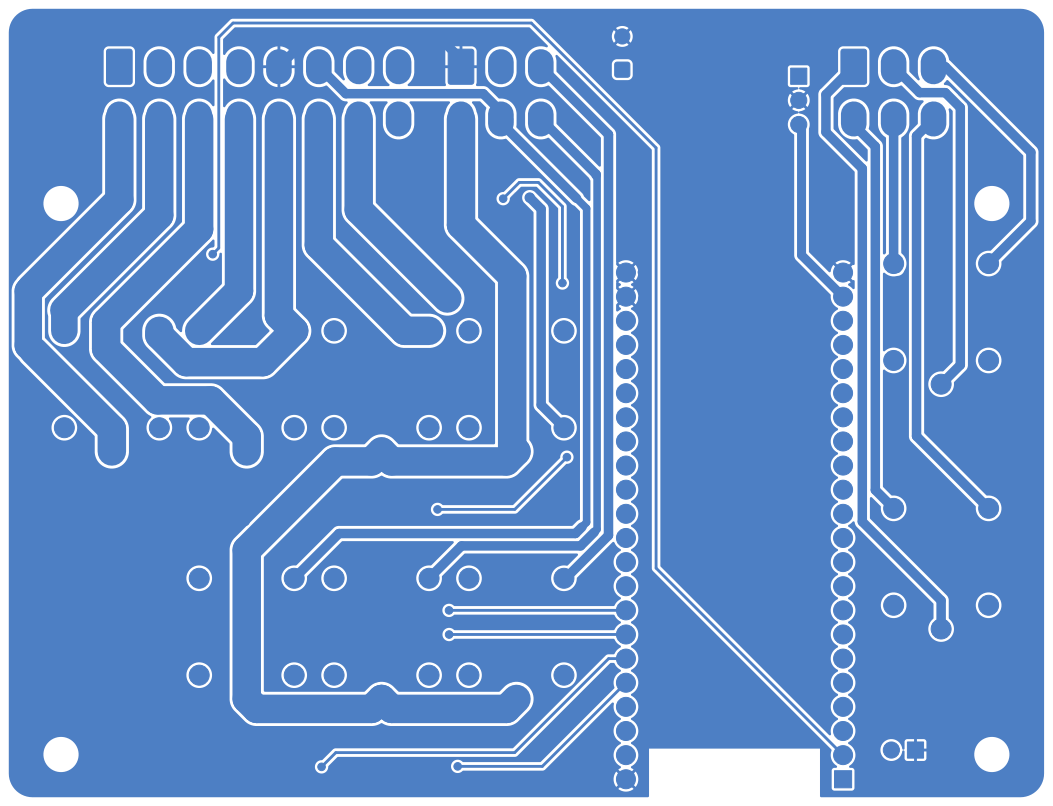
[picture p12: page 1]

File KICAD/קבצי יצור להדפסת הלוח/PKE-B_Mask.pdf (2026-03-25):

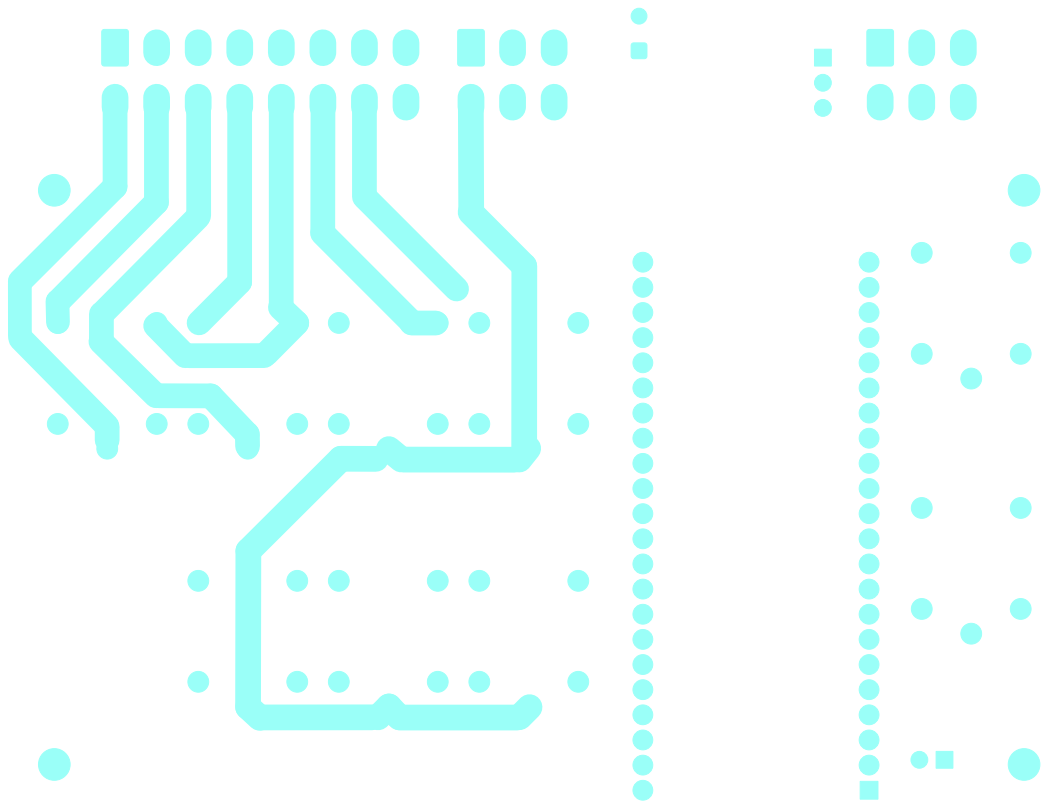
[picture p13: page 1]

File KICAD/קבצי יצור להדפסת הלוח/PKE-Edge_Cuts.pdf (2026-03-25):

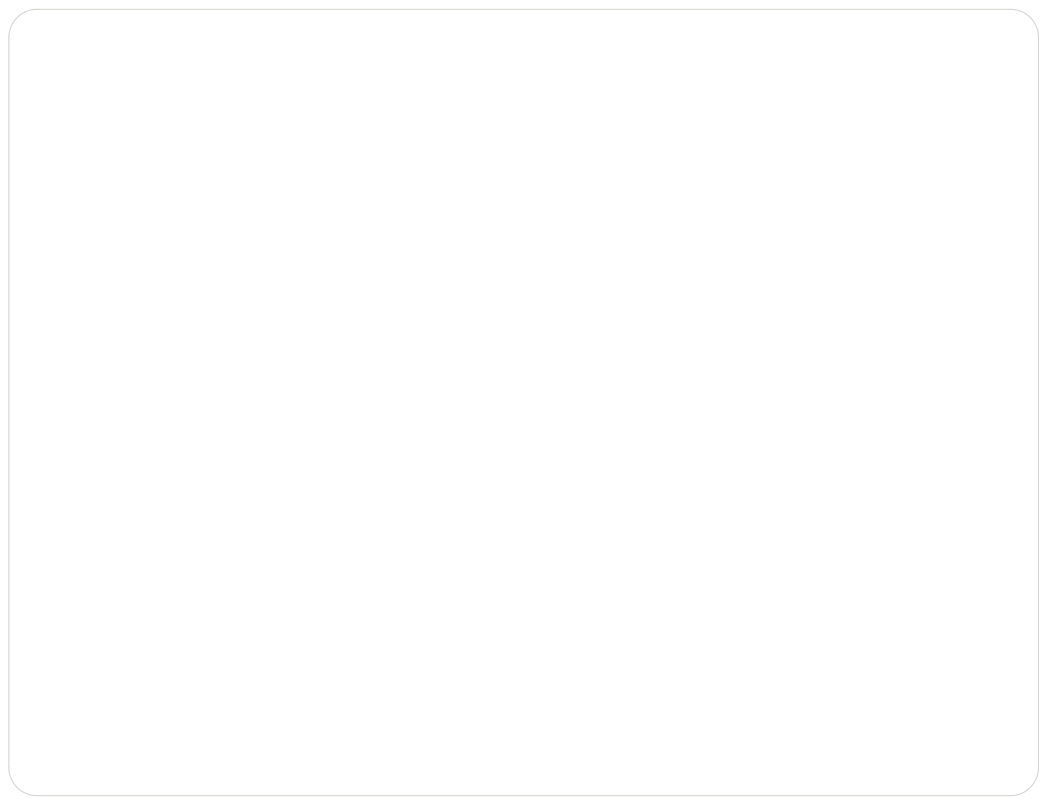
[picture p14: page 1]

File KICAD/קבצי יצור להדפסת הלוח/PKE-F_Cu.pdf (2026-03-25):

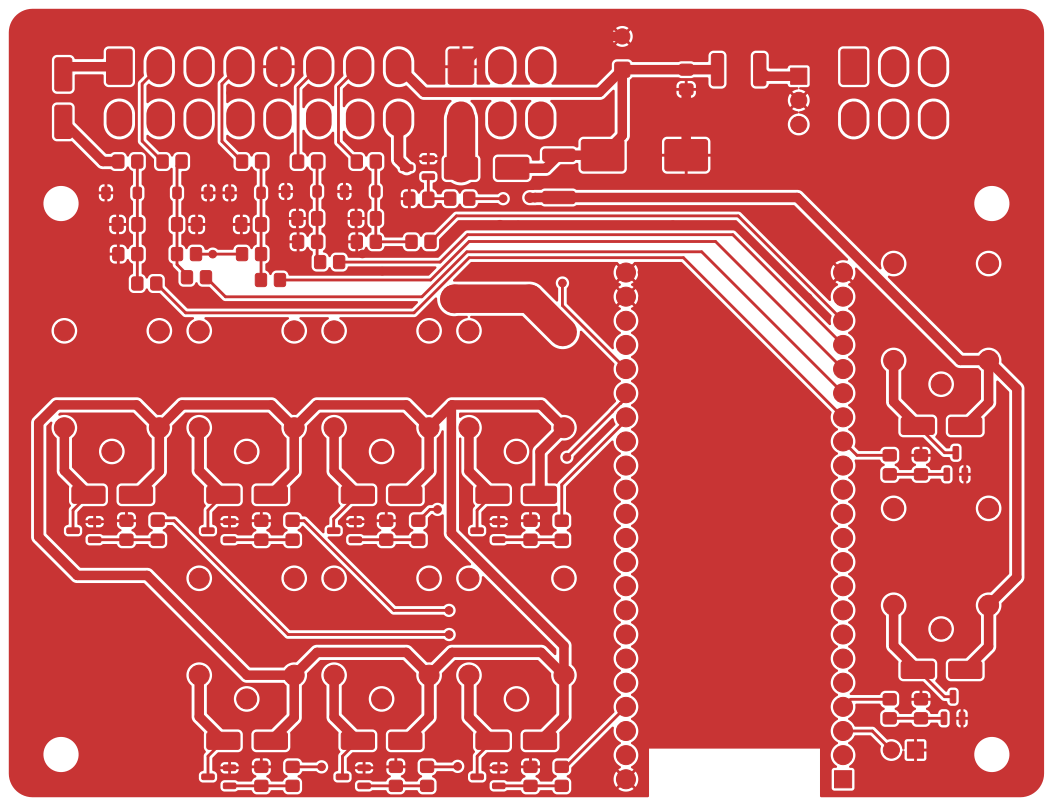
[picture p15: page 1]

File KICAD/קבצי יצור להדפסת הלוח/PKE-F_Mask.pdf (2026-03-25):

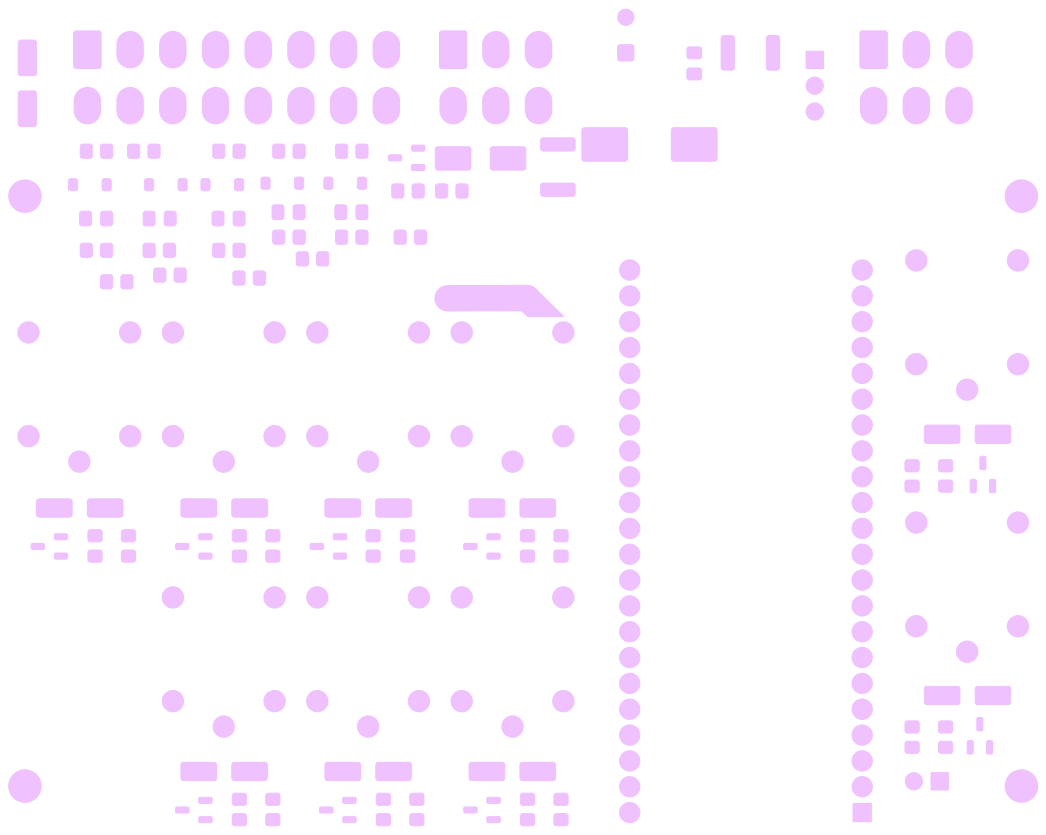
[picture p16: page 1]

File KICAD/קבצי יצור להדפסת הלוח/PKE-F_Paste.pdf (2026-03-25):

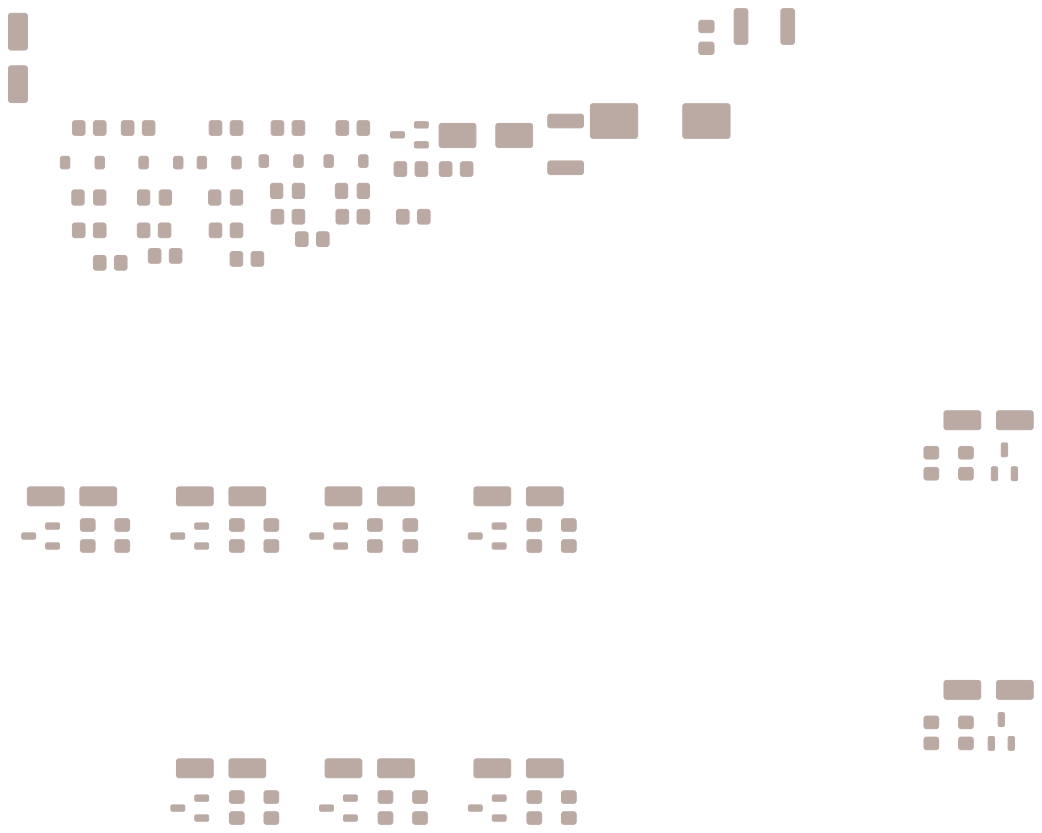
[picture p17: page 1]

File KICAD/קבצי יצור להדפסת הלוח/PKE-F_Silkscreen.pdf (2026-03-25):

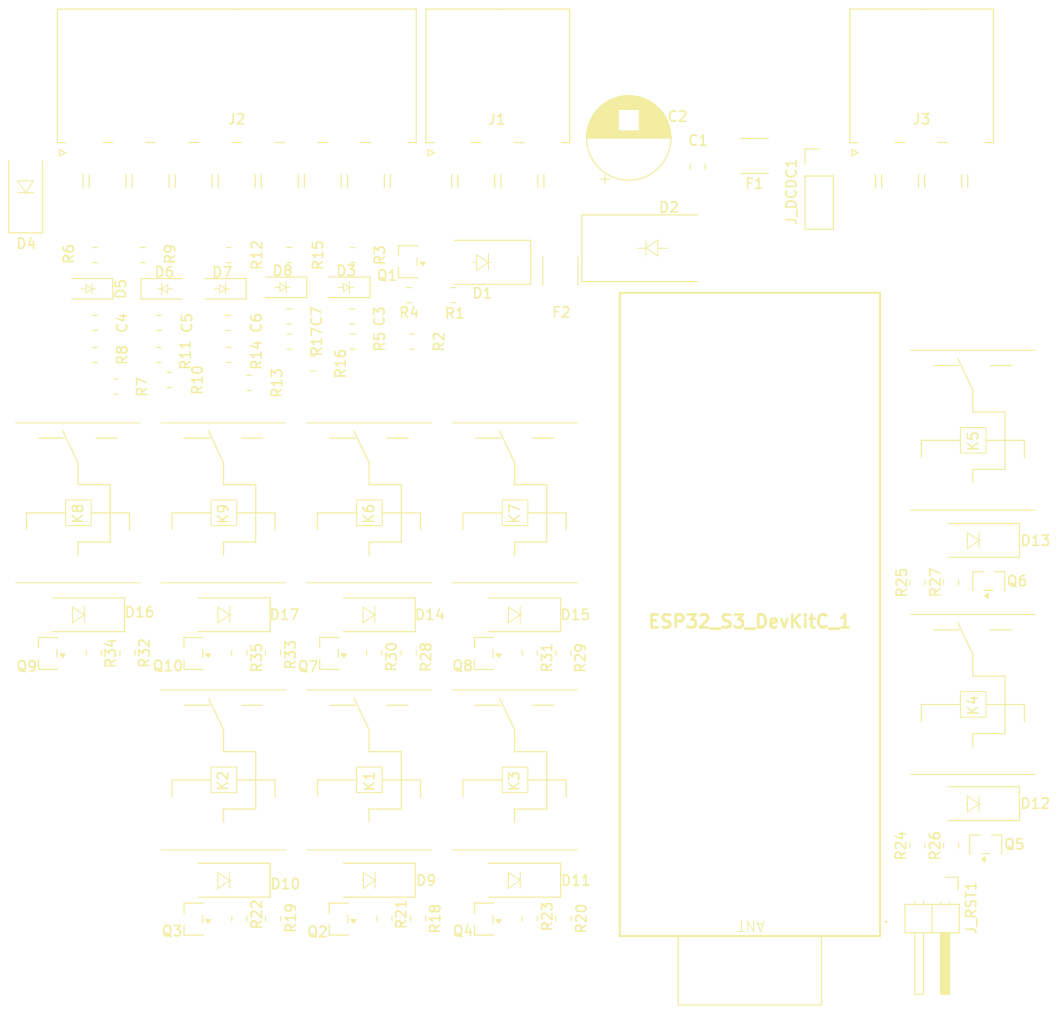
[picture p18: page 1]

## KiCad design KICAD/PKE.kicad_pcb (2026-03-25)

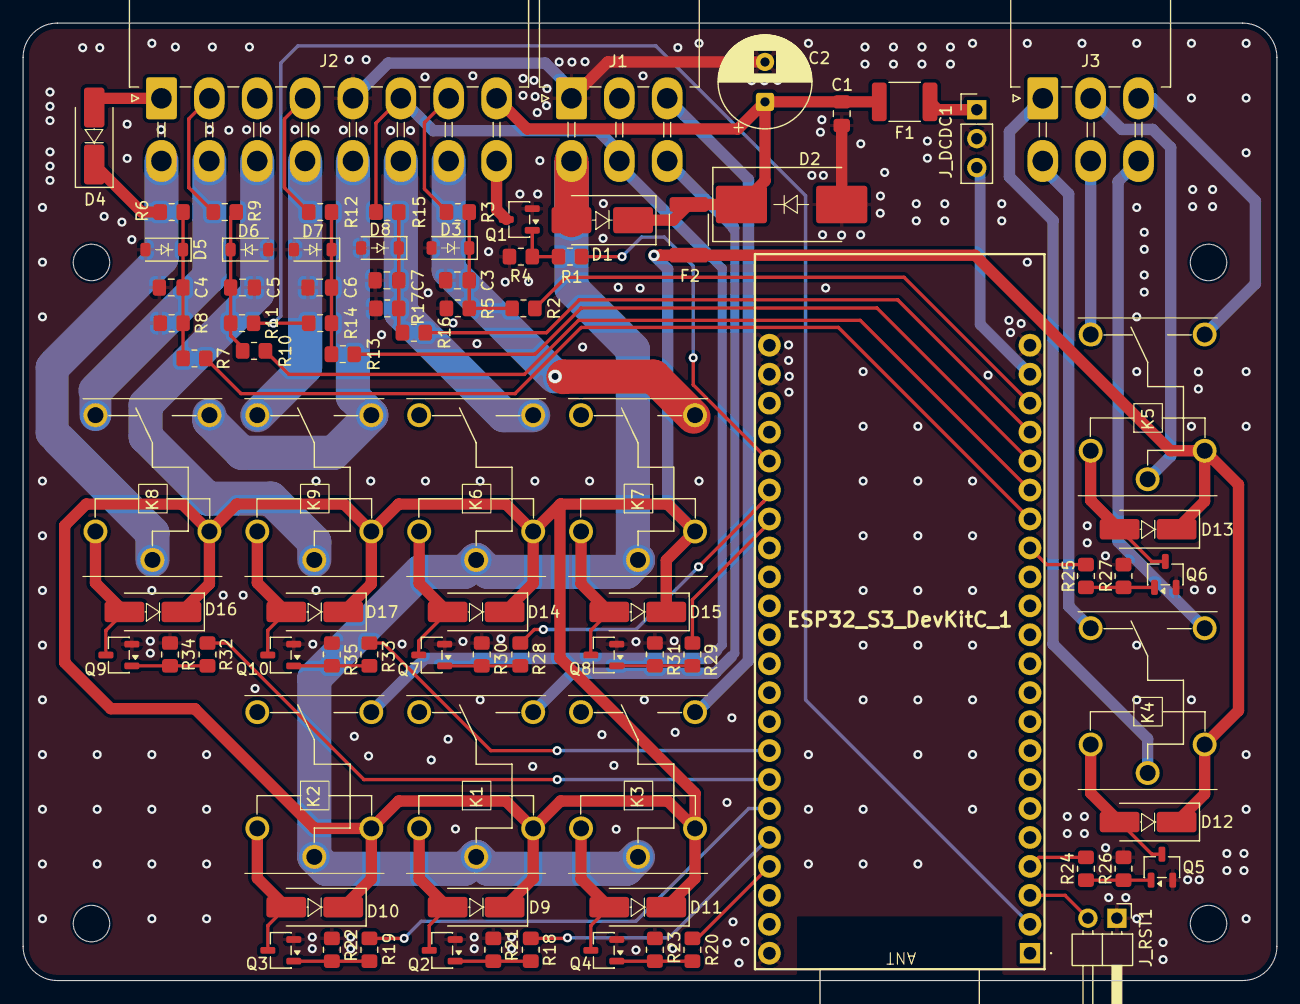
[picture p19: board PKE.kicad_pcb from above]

Board: 2 copper layers, 110.0 x 84.0 mm, 90 parts (0 on the bottom side), 69 nets.

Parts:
C1, C3, C4, C5, C6, C7: 100n; C_0805_2012Metric_Pad1.18x1.45mm_HandSolder
C2: 50V220u; CP_Radial_D8.0mm_P3.50mm
D1: SR560; D_SMB_Handsoldering
D2: P6KE18A; D_SMC_Handsoldering
D3, D5, D6, D7, D8: 1N4728A; D_SOD-123
D4, D9, D10, D11, D12, D13, D14, D15, D16, D17: 1N4007; D_SMA_Handsoldering
ESP32_S3_DevKitC_1: ESP32_S3_DevKitC; ESP32S3DevKitC1N32R16V
F1: FUSE_DCDC 1.1A; Fuse_1812_4532Metric_Pad1.30x3.40mm_HandSolder
F2: FUSE_COILS 1.1A; Fuse_1812_4532Metric_Pad1.30x3.40mm_HandSolder
H1, H2, H3, H4: MountingHole; MountingHole_3.2mm_M3
J1, J3: Conn_01x06; Molex_Mini-Fit_Jr_5569-06A2_2x03_P4.20mm_Horizontal
J2: Conn_01x14; Molex_Mini-Fit_Jr_5569-16A2_2x08_P4.20mm_Horizontal
J_DCDC1: Conn_01x03; PinHeader_1x03_P2.54mm_Vertical
J_RST1: Conn_01x02; PinHeader_1x02_P2.54mm_Horizontal
K1, K2, K3, K4, K5, K6, K7, K8, K9: CMA51H-S-DC12V-C; CMA51HSDC12VC
Q1, Q2, Q3, Q4, Q5, Q6, Q7, Q8, Q9, Q10: 2N2222A; SOT-23-3
R1, R2, R7, R10, R13, R16, R18, R19, R20, R24, R25, R28, R29, R32, R33: 1k; R_0805_2012Metric_Pad1.20x1.40mm_HandSolder
R3, R6, R15: 30k; R_0805_2012Metric_Pad1.20x1.40mm_HandSolder
R4, R21, R22, R23, R26, R27, R30, R31, R34, R35: 100k; R_0805_2012Metric_Pad1.20x1.40mm_HandSolder
R5, R8, R17: 10k; R_0805_2012Metric_Pad1.20x1.40mm_HandSolder
R9, R12: 4.7k; R_0805_2012Metric_Pad1.20x1.40mm_HandSolder
R11, R14: 47k; R_0805_2012Metric_Pad1.20x1.40mm_HandSolder

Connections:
3V3: ESP32_S3_DevKitC_1.2 (3V3_2), R11.1, R14.1
+5V: ESP32_S3_DevKitC_1.21 (5V), J_DCDC1.3
+12V_COILS: D9.1 (K), D10.1 (K), D11.1 (K), D12.1 (K), D13.1 (K), D14.1 (K), D15.1 (K), D16.1 (K), D17.1 (K), F2.1, K1.3 (COIL_2), K2.3 (COIL_2), K3.3 (COIL_2), K4.3 (COIL_2), K5.3 (COIL_2), K6.3 (COIL_2), K7.3 (COIL_2), K8.3 (COIL_2), K9.3 (COIL_2)
+12V_ELEC: C1.2, C2.1, D1.1 (K), D2.1 (K), F1.2, F2.2, J2.8
+12V_MIRROR_IN: J2.13, K8.5 (NO), K9.5 (NO)
+12V_RAW: D1.2 (A), J1.4, K1.2 (COM), K2.2 (COM), K3.2 (COM), K6.2 (COM), K7.2 (COM)
ACC: ESP32_S3_DevKitC_1.27 (2), R18.2
ACC_OUT: J1.6, K1.5 (NO)
BRAKE_12V: D4.1 (K), R6.1
BRAKE_SIG: ESP32_S3_DevKitC_1.16 (10), R7.1
BTN_GND: J2.16, Q1.3 (C)
BTN_LED: ESP32_S3_DevKitC_1.40 (21), R1.2
BTN_SIG: ESP32_S3_DevKitC_1.20 (14), R2.2
BTN_TRIG: J2.7, R3.2
DOOR_NEG: J2.4, R12.1
DOOR_SIG: ESP32_S3_DevKitC_1.18 (12), R13.1
GND: C1.1, C2.2, C3.1, C4.1, C5.1, C6.1, C7.1, D2.2 (A), D3.2 (A), D5.2 (A), D6.2 (A), D7.2 (A), D8.2 (A), ESP32_S3_DevKitC_1.22 (G_1), ESP32_S3_DevKitC_1.23 (G_2), ESP32_S3_DevKitC_1.43 (G_3), ESP32_S3_DevKitC_1.44 (G_4), J1.1, J2.5, J_DCDC1.2, J_RST1.1, Q1.2 (E), Q2.2 (E), Q3.2 (E), Q4.2 (E), Q5.2 (E), Q6.2 (E), Q7.2 (E), Q8.2 (E), Q9.2 (E), Q10.2 (E), R4.2, R5.1, R8.1, R17.1, R21.2, R22.2, R23.2, R26.2, R27.2, R30.2, R31.2, R34.2, R35.2
HB_NEG: J2.2, R9.1
HB_SIG: ESP32_S3_DevKitC_1.17 (11), R10.1
IGN: ESP32_S3_DevKitC_1.28 (42), R19.2
IGN_OUT: J1.5, J2.6, K2.5 (NO), R15.1
IGN_SIG: ESP32_S3_DevKitC_1.19 (13), R16.1
LOCK: ESP32_S3_DevKitC_1.4, R24.2
LOCK_COM: J3.1, K4.2 (COM)
LOCK_NC: J3.4, K4.4 (NC)
LOCK_NO: J3.6, K4.5 (NO)
L_BLINK: ESP32_S3_DevKitC_1.38 (48), R29.2
L_BLINK_OUT: J2.15, K7.5 (NO)
MIRROR_CLOSE: ESP32_S3_DevKitC_1.29 (41), R32.2
MIRROR_CLOSE_MOTOR: J2.9, K8.2 (COM)
MIRROR_CLOSE_SW: J2.10, K8.4 (NC)
MIRROR_OPEN: ESP32_S3_DevKitC_1.30 (40), R33.2
MIRROR_OPEN_MOTOR: J2.11, K9.2 (COM)
MIRROR_OPEN_SW: J2.12, K9.4 (NC)
unnamed: C3.2, D3.1 (K), R2.1, R3.1, R5.2
unnamed: D4.2 (A), J2.1
unnamed: C4.2, D5.1 (K), R6.2, R7.2, R8.2
unnamed: C5.2, D6.1 (K), R9.2, R10.2, R11.2
unnamed: C6.2, D7.1 (K), R12.2, R13.2, R14.2
unnamed: C7.2, D8.1 (K), R15.2, R16.2, R17.2
unnamed: D9.2 (A), K1.1 (COIL_1), Q2.3 (C)
unnamed: D10.2 (A), K2.1 (COIL_1), Q3.3 (C)
unnamed: D11.2 (A), K3.1 (COIL_1), Q4.3 (C)
unnamed: D12.2 (A), K4.1 (COIL_1), Q5.3 (C)
unnamed: D13.2 (A), K5.1 (COIL_1), Q6.3 (C)
unnamed: D14.2 (A), K6.1 (COIL_1), Q7.3 (C)
unnamed: D15.2 (A), K7.1 (COIL_1), Q8.3 (C)
unnamed: D16.2 (A), K8.1 (COIL_1), Q9.3 (C)
unnamed: D17.2 (A), K9.1 (COIL_1), Q10.3 (C)
unnamed: F1.1, J_DCDC1.1
unnamed: Q1.1 (B), R1.1, R4.1
unnamed: Q2.1 (B), R18.1, R21.1
unnamed: Q3.1 (B), R19.1, R22.1
unnamed: Q4.1 (B), R20.1, R23.1
unnamed: Q5.1 (B), R24.1, R26.1
unnamed: Q6.1 (B), R25.1, R27.1
unnamed: Q7.1 (B), R28.1, R30.1
unnamed: Q8.1 (B), R29.1, R31.1
unnamed: Q9.1 (B), R32.1, R34.1
unnamed: Q10.1 (B), R33.1, R35.1
RST: ESP32_S3_DevKitC_1.3 (RST), J_RST1.2
R_BLINK: ESP32_S3_DevKitC_1.39 (47), R28.2
R_BLINK_OUT: J2.14, K6.5 (NO)
START: ESP32_S3_DevKitC_1.26 (1), R20.2
START_OUT: J1.3, K3.5 (NO)
UNLOCK: ESP32_S3_DevKitC_1.15 (9), R25.2
UNLOCK_COM: J3.2, K5.2 (COM)
UNLOCK_NC: J3.5, K5.4 (NC)
UNLOCK_NO: J3.3, K5.5 (NO)

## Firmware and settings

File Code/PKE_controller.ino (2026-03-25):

#include <Arduino.h>
#include <BLEDevice.h>
#include <BLEUtils.h>
#include <BLEScan.h>
#include <BLEAdvertisedDevice.h>

// ==========================================
// 1. הגדרות מצבי עבודה
// ==========================================
bool USE_PHYSICAL_INPUTS = true;

// ==========================================
// 2. הגדרת פינים (GPIO מדויק)
// ==========================================
const int PIN_BRAKE_SIG    = 10;
const int PIN_HB_SIG       = 11;
const int PIN_DOOR_SIG     = 12;
const int PIN_IGN_SIG      = 13;
const int PIN_BTN_SIG      = 14;

const int PIN_LOCK         = 4;
const int PIN_UNLOCK       = 9;
const int PIN_START        = 1;
const int PIN_ACC          = 2;
const int PIN_IGN          = 42;
const int PIN_MIRROR_CLOSE = 41;
const int PIN_MIRROR_OPEN  = 40;
const int PIN_L_BLINK      = 48;
const int PIN_R_BLINK      = 47;
const int PIN_BTN_LED      = 21;

// ==========================================
// 3. ערכי זמן קבועים
// ==========================================
const unsigned long DEBOUNCE_DELAY            = 50;
const unsigned long LOCK_PULSE                = 500;
const unsigned long UNLOCK_PULSE              = 500;
const unsigned long LOCK_BLINK_DURATION       = 3000;
const int           UNLOCK_BLINK_COUNT        = 3;
const unsigned long UNLOCK_BLINK_ON_TIME      = 333;
const unsigned long UNLOCK_BLINK_OFF_TIME     = 333;
const int           LOCK_FAIL_BLINK_COUNT     = 5;
const unsigned long LOCK_FAIL_BLINK_ON_TIME   = 333;
const unsigned long LOCK_FAIL_BLINK_OFF_TIME  = 333;
const unsigned long LED_BLINK_ON_TIME         = 333;
const unsigned long LED_BLINK_OFF_TIME        = 333;
const int           LED_ERROR_BLINK_COUNT     = 4;
const unsigned long LED_ERROR_BLINK_ON_TIME   = 333;
const unsigned long LED_ERROR_BLINK_OFF_TIME  = 333;
const unsigned long MIRROR_OPEN_PULSE         = 3000;
const unsigned long MIRROR_CLOSE_PULSE        = 3000;
const unsigned long PRE_START_DELAY           = 1000;    // תמיד 1s לפני START — FR-17, FR-18
const unsigned long START_PULSE               = 1500;
const unsigned long EMERGENCY_STOP_PRESS      = 5000;
const unsigned long ACC_IGN_AUTO_OFF_TIMEOUT  = 300000; // 5 דקות — FR-35
const unsigned long IGN_OFF_FILTER_TIME       = 200;    // סינון יציאה ממפתח מקורי — FR-15

// ==========================================
// 4. הגדרות BLE (כולל סינון FR-02/03)
// ==========================================
// TODO: >>> חובה להזין את ה-MAC האמיתי של תג ה-Feasycom כאן לפני צריבה לחומרה <
const String TARGET_MAC = "dc:0d:30:2b:84:8f";

const int RSSI_NEAR_THRESHOLD = -70;
const int RSSI_FAR_THRESHOLD  = -85;
const unsigned long BLE_TIMEOUT     = 2000;
const unsigned long RSSI_FILTER_TIME = 1000; // סינון תנודות RSSI — FR-02, FR-03

unsigned long lastBleSeenTime = 0;
int currentRssi = -100;
bool isKeyPresent = false;

unsigned long rssiThresholdStartTime = 0;
bool isRssiInNearZone = false;
bool isRssiInFarZone  = false;

// ==========================================
// 5. הגדרת מצבי המערכת
// ==========================================
// IDLE: מצב מעבר רגעי בלבד — אינו מצב שהייה. מנתב ל-LOCKED/UNLOCKED מיד.
enum SystemState {
  STATE_IDLE,
  STATE_LOCKED,
  STATE_UNLOCKED,
  STATE_ACC_ON,
  STATE_IGN_ON,
  STATE_CRANKING,
  STATE_ENGINE_RUNNING,
  STATE_ORIGINAL_KEY_ACTIVE
};

SystemState currentState = STATE_IDLE;

// ==========================================
// 6. משתנים גלובליים
// ==========================================
bool brakePressed       = false;
bool hbPulled           = false;
bool isDoorOpen         = false;
bool originalIgnActive  = false;
bool btnPressed         = false;
bool lastBtnPressed     = false;

bool ledSuppressedAfterShutdown = false;
bool prevBrakeState = false;
bool prevKeyPresent = false;

bool espControlsIgnition = false;
bool lockFailNotified    = false;

unsigned long btnPressStartTime       = 0;
unsigned long stateEnterTime          = 0;
unsigned long keyLostStartTime        = 0; // FR-35
unsigned long originalIgnOffStartTime = 0; // FR-15
unsigned long ignReleasedByEspTime = 0;
const unsigned long IGN_TAKEOVER_GUARD_TIME = 700;

struct InputState {
  bool currentState;
  bool lastReading;
  unsigned long lastDebounceTime;
};
InputState brakeState = {false, false, 0};
InputState hbState    = {false, false, 0};
InputState doorState  = {false, false, 0};
InputState ignState   = {false, false, 0};
InputState btnState   = {false, false, 0};

// -- ניהול פלטים ברקע --
unsigned long lockActionStartTime = 0;
bool isLocking   = false;
bool isUnlocking = false;

bool isLockFailSequence = false;
int  lockFailStep       = 0;
unsigned long lockFailTimer = 0;

unsigned long mirrorActionStartTime = 0;
bool isMirrorOpening = false;
bool isMirrorClosing = false;

unsigned long blinkerLastToggleTime = 0;
int  blinkerToggleCount   = 0;
int  blinkerTargetToggles = 0;
bool isBlinking       = false;
bool isSolidBlink     = false;
unsigned long currentBlinkOnTime  = 0;
unsigned long currentBlinkOffTime = 0;

unsigned long btnLedLastToggle   = 0;
int  btnLedToggleCount           = 0;
int  btnLedTargetToggles         = 0;
bool isBtnLedBlinking            = false;
bool btnLedBaseState             = false;
unsigned long currentLedOnTime   = 0;
unsigned long currentLedOffTime  = 0;

// ==========================================
// 7. פונקציות עזר
// ==========================================

class MyAdvertisedDeviceCallbacks: public BLEAdvertisedDeviceCallbacks {
    void onResult(BLEAdvertisedDevice advertisedDevice) {
      String seenMac = advertisedDevice.getAddress().toString().c_str();

      if (seenMac == TARGET_MAC) {
        currentRssi = advertisedDevice.getRSSI();
        lastBleSeenTime = millis();

        /*Serial.print("TARGET FOUND | MAC: ");
        Serial.print(seenMac);
        Serial.print(" | RSSI: ");
        Serial.println(currentRssi);*/
      }
    }
};

// סינון RSSI עם היסטרזיס — FR-02, FR-03
void updateBLELogic() {
  if (!USE_PHYSICAL_INPUTS) return;

  unsigned long now = millis();
  if (now - lastBleSeenTime > BLE_TIMEOUT) currentRssi = -100;

  if (currentRssi >= RSSI_NEAR_THRESHOLD) {
    if (!isRssiInNearZone) { isRssiInNearZone = true; rssiThresholdStartTime = now; }
    isRssiInFarZone = false;
  } else if (currentRssi <= RSSI_FAR_THRESHOLD) {
    if (!isRssiInFarZone) { isRssiInFarZone = true; rssiThresholdStartTime = now; }
    isRssiInNearZone = false;
  } else {
    // שטח מת — ללא שינוי מצב
    isRssiInNearZone = false;
    isRssiInFarZone  = false;
  }

  if (!isKeyPresent && isRssiInNearZone && (now - rssiThresholdStartTime >= RSSI_FILTER_TIME)) {
    isKeyPresent = true;
    Serial.print(">>> BLE KEY DETECTED (NEAR), RSSI = ");
    Serial.print(currentRssi);
    Serial.println(" <<<");
  } else if (isKeyPresent && isRssiInFarZone && (now - rssiThresholdStartTime >= RSSI_FILTER_TIME)) {
    isKeyPresent = false;
    Serial.print(">>> BLE KEY LOST (FAR), RSSI = ");
    Serial.print(currentRssi);
    Serial.println(" <<<");
  }
}

void setRelay(int pin, bool state) {
  if (digitalRead(pin) != state) {
    digitalWrite(pin, state ? HIGH : LOW);
    if (pin == PIN_IGN) {
      espControlsIgnition = state;
      if (!state) {
        ignReleasedByEspTime = millis();
      }
    }
  }
}

void changeState(SystemState newState) {
  currentState   = newState;
  stateEnterTime = millis();
  Serial.print(">>> NEW STATE: ");
  Serial.println(newState);
}

void debounceInput(int pin, InputState &input, bool &outputFlag, bool activeHigh) {
  bool reading        = digitalRead(pin);
  bool logicalReading = activeHigh ? reading : !reading;
  if (logicalReading != input.lastReading) input.lastDebounceTime = millis();
  if ((millis() - input.lastDebounceTime) > DEBOUNCE_DELAY) {
    if (logicalReading != input.currentState) {
      input.currentState = logicalReading;
      outputFlag         = input.currentState;
    }
  }
  input.lastReading = logicalReading;
}

void readAllInputs() {
  debounceInput(PIN_BRAKE_SIG, brakeState, brakePressed,      true);
  debounceInput(PIN_HB_SIG,    hbState,    hbPulled,          false); // טריגר שלילי
  debounceInput(PIN_DOOR_SIG,  doorState,  isDoorOpen,        true);
  debounceInput(PIN_IGN_SIG,   ignState,   originalIgnActive, true);
  debounceInput(PIN_BTN_SIG,   btnState,   btnPressed,        true);
}

// סימולציה דרך Serial לבדיקות ללא חומרה
void readSerialSimulation() {
  if (Serial.available() > 0) {
    char c = Serial.read();
    switch(c) {
      case 'k': isKeyPresent      = !isKeyPresent;      break;
      case 'p': btnPressed        = !btnPressed;        break;
      case 'b': brakePressed      = !brakePressed;      break;
      case 'h': hbPulled          = !hbPulled;          break;
      case 'd': isDoorOpen        = !isDoorOpen;        break;
      case 'i': originalIgnActive = !originalIgnActive; break;
    }
  }
}

// --- טריגרים לפלטים ---

// FR-04, FR-06, FR-08: פתיחה + מראות + 3 הבהובים
void triggerUnlockSequence() {
  isUnlocking = true; lockActionStartTime = millis();
  isMirrorOpening = true; mirrorActionStartTime = millis();
  isBlinking = true; isSolidBlink = false;
  blinkerToggleCount    = 0;
  blinkerTargetToggles  = UNLOCK_BLINK_COUNT * 2;
  currentBlinkOnTime    = UNLOCK_BLINK_ON_TIME;
  currentBlinkOffTime   = UNLOCK_BLINK_OFF_TIME;
  blinkerLastToggleTime = millis();
  setRelay(PIN_L_BLINK, true); setRelay(PIN_R_BLINK, true);
}

// FR-12 (תרחיש 16): UNLOCK בלבד ליישור פיזי — ללא מראות וללא הבהובים
// מיועדת לשימוש לאחר ביטול רצף פעיל (cancelLockFailSequence) בלבד
void triggerUnlockOnlySequence() {
  isUnlocking = true;
  lockActionStartTime = millis();
}

// FR-05, FR-07, FR-09: נעילה + מראות + איתות רציף 3 שניות
void triggerLockSequence() {
  isLocking = true; lockActionStartTime = millis();
  isMirrorClosing = true; mirrorActionStartTime = millis();
  isBlinking = true; isSolidBlink = true;
  blinkerLastToggleTime = millis();
  setRelay(PIN_L_BLINK, true); setRelay(PIN_R_BLINK, true);
}

void triggerLockFailureBlinks() {
  isBlinking = true; isSolidBlink = false;
  blinkerToggleCount    = 0;
  blinkerTargetToggles  = LOCK_FAIL_BLINK_COUNT * 2;
  currentBlinkOnTime    = LOCK_FAIL_BLINK_ON_TIME;
  currentBlinkOffTime   = LOCK_FAIL_BLINK_OFF_TIME;
  blinkerLastToggleTime = millis();
  setRelay(PIN_L_BLINK, true); setRelay(PIN_R_BLINK, true);
}

// FR-10, FR-11: כישלון נעילה — LOCK פולס ואז UNLOCK פולס + 5 הבהובים
// המראות לא זזות בכלל — FR-10: בכישלון נעילה מראות לא מתקפלות
// יש לוודא שלפני הכניסה לרצף זה לא נשאר רצף PKE סותר פעיל - SR-12, SW-04
void triggerLockFailureSequence() {
  isLockFailSequence = true;
  lockFailStep       = 1;
  lockFailTimer      = millis();
  setRelay(PIN_LOCK, true);
  // ללא isMirrorClosing — FR-10: בכישלון נעילה מראות לא זזות
}

// עוצר את כל רצפי ה-PKE הפעילים ומכבה פלטים — SR-12, SW-04
// יש לקרוא לפני כל triggerLock/Unlock/LockFailure כדי למנוע חפיפות
void cancelAllPKESequences() {
  isLocking          = false;
  isUnlocking        = false;
  isLockFailSequence = false;
  lockFailStep       = 0;
  lockFailNotified   = false;
  setRelay(PIN_LOCK,   false);
  setRelay(PIN_UNLOCK, false);

  isMirrorOpening = false;
  isMirrorClosing = false;
  setRelay(PIN_MIRROR_OPEN,  false);
  setRelay(PIN_MIRROR_CLOSE, false);

  isBlinking = false;
  setRelay(PIN_L_BLINK, false);
  setRelay(PIN_R_BLINK, false);
}

// ביטול רצף כישלון נעילה — עוצר את כל ה-PKE
void cancelLockFailSequence() {
  cancelAllPKESequences();
}

void triggerLedFeedback() {
  isBtnLedBlinking    = true;
  btnLedToggleCount   = 0;
  btnLedTargetToggles = 2; // הבהוב קצר אחד (ON+OFF) — FR-26
  currentLedOnTime    = LED_BLINK_ON_TIME;
  currentLedOffTime   = LED_BLINK_OFF_TIME;
  btnLedLastToggle    = millis();
  setRelay(PIN_BTN_LED, !btnLedBaseState);
}

void triggerLedError() {
  isBtnLedBlinking    = true;
  btnLedToggleCount   = 0;
  btnLedTargetToggles = LED_ERROR_BLINK_COUNT * 2; // 4 הבהובי שגיאה — FR-27, FR-28
  currentLedOnTime    = LED_ERROR_BLINK_ON_TIME;
  currentLedOffTime   = LED_ERROR_BLINK_OFF_TIME;
  btnLedLastToggle    = millis();
  setRelay(PIN_BTN_LED, true);
}
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
void loop() {
  lastBtnPressed = btnPressed;

  if (USE_PHYSICAL_INPUTS) {
    readAllInputs();    // SW-02
    updateBLELogic();
  } else {
    readSerialSimulation();
  }

  bool btnJustPressed = (btnPressed && !lastBtnPressed);

  // FR-35: טיימר מבוסס רגע היעלמות המפתח (לא רגע כניסה למצב)
  if (!isKeyPresent && keyLostStartTime == 0) {
    keyLostStartTime = millis();
  } else if (isKeyPresent) {
    keyLostStartTime = 0;
  }

  // FR-23: שחרור חסימת LED בעקבות פעילות חדשה
  if (brakePressed && !prevBrakeState) ledSuppressedAfterShutdown = false;
  if (isKeyPresent  && !prevKeyPresent) ledSuppressedAfterShutdown = false;
  if (btnJustPressed)                   ledSuppressedAfterShutdown = false;

  prevBrakeState = brakePressed;
  prevKeyPresent = isKeyPresent;

  if (isKeyPresent || !isDoorOpen) lockFailNotified = false;

  // FR-13: זיהוי שליטת מפתח מקורי
  // SR-12, FR-13: מבטל את כל רצפי ה-PKE הפעילים לפני הכניסה
  if (originalIgnActive &&
    !espControlsIgnition &&
    currentState != STATE_ORIGINAL_KEY_ACTIVE &&
    (millis() - ignReleasedByEspTime > IGN_TAKEOVER_GUARD_TIME)) {
  cancelAllPKESequences();
  changeState(STATE_ORIGINAL_KEY_ACTIVE);
  handleOutputs();
  return;
  }

  switch (currentState) {

    // STATE_IDLE: מצב מעבר רגעי — FR-37, SR-08
    // מאפס פלטים ומנתב מיד ל-LOCKED או UNLOCKED, אינו מצב שהייה
    case STATE_IDLE:
      setRelay(PIN_ACC,   false);
      setRelay(PIN_IGN,   false);
      setRelay(PIN_START, false);
      if (isKeyPresent) {
        triggerUnlockSequence();
        changeState(STATE_UNLOCKED);
      } else {
        changeState(STATE_LOCKED);
      }
      break;

    // STATE_LOCKED: אין מפתח, רכב נעול
    case STATE_LOCKED:
      setRelay(PIN_ACC,   false);
      setRelay(PIN_IGN,   false);
      setRelay(PIN_START, false);
      if (isKeyPresent) {
        // SR-12: מבטל פולס LOCK שעלול עדיין לרוץ לפני פתיחה
        cancelAllPKESequences();
        triggerUnlockSequence(); // FR-04, FR-06, FR-08
        changeState(STATE_UNLOCKED);
        break;
      }
      if (btnJustPressed) triggerLedError(); // FR-27, FR-28
      break;

    // STATE_UNLOCKED: רכב פתוח וכבוי, ממתין לפעולת משתמש או להחלטת PKE
    // (אפשר להיות כאן גם ללא מפתח — אחרי אובדן מפתח, אחרי כישלון נעילה, אחרי כיבוי)
    case STATE_UNLOCKED:
      setRelay(PIN_ACC,   false);
      setRelay(PIN_IGN,   false);
      setRelay(PIN_START, false);

      // ניהול רצף כישלון נעילה פעיל — SW-05, FR-12 (תרחיש 16)
      if (isLockFailSequence) {
        if (!isDoorOpen && !isKeyPresent) {
          // דלת נסגרה באמצע — מבטל הכל ונועל רגיל — FR-12
          cancelLockFailSequence();
          triggerLockSequence(); // FR-05, FR-07, FR-09
          changeState(STATE_LOCKED);
          break;
        }
        if (isKeyPresent) {
          // מפתח חזר באמצע — UNLOCK בלבד ליישור פיזי — FR-12
          // לא triggerUnlockSequence כי המראות לא נסגרו
          cancelLockFailSequence();
          triggerUnlockOnlySequence();
          changeState(STATE_UNLOCKED);
          break;
        }
        break;
      }

      // SR-11: PKE פעיל רק כשמצב ההנעה כבוי (LOCKED/UNLOCKED)
      if (!isKeyPresent) {
        if (isDoorOpen) {
          // FR-10, FR-11, SR-04: כישלון נעילה — LOCK+UNLOCK בלבד, מראות לא זזות
          // SR-12, SW-04: מבטל רצף PKE קודם שאולי עדיין רץ לפני כניסה לרצף חדש
          if (!lockFailNotified) {
            cancelAllPKESequences();
            triggerLockFailureSequence();
            lockFailNotified = true;
          }
        } else {
          // SR-12: מבטל פולס UNLOCK שעלול עדיין לרוץ לפני נעילה
          cancelAllPKESequences();
          triggerLockSequence(); // FR-05, FR-07, FR-09
          changeState(STATE_LOCKED);
          lockFailNotified = false;
          break;
        }
      }

      if (btnJustPressed) {
        if (isKeyPresent) {
          if (brakePressed && hbPulled) {
            triggerLedFeedback();
            changeState(STATE_CRANKING); // FR-16, FR-17, FR-18: תמיד 1s
          } else {
            triggerLedFeedback();
            changeState(STATE_ACC_ON); // FR-25
          }
        } else {
          triggerLedError(); // FR-27, FR-28
        }
      }
      break;

    // STATE_ACC_ON: ACC פעיל, IGN כבוי
    case STATE_ACC_ON:
      setRelay(PIN_ACC, true);

      // FR-35: כיבוי אוטומטי אחרי 5 דקות ללא מפתח
      if (!isKeyPresent && keyLostStartTime > 0 &&
          (millis() - keyLostStartTime > ACC_IGN_AUTO_OFF_TIMEOUT)) {
        setRelay(PIN_ACC, false);
        ledSuppressedAfterShutdown = true;
        changeState(STATE_UNLOCKED);
        break;
      }

      if (btnJustPressed) {
        if (isKeyPresent) {
          if (brakePressed && hbPulled) {
            triggerLedFeedback();
            changeState(STATE_CRANKING); // FR-16, FR-17, FR-18
          } else {
            triggerLedFeedback();
            changeState(STATE_IGN_ON); // FR-25
          }
        } else {
          // FR-32: כיבוי מ-ACC ללא ברקס מותר כשהמנוע לא פועל (גם אחרי אובדן מפתח)
          triggerLedFeedback();
          setRelay(PIN_ACC, false);
          ledSuppressedAfterShutdown = true;
          changeState(STATE_UNLOCKED);
        }
      }
      break;

    // STATE_IGN_ON: ACC + IGN פעילים, מנוע לא פועל
    case STATE_IGN_ON:
      setRelay(PIN_ACC, true);
      setRelay(PIN_IGN, true);

      // FR-35: כיבוי אוטומטי אחרי 5 דקות ללא מפתח
      if (!isKeyPresent && keyLostStartTime > 0 &&
          (millis() - keyLostStartTime > ACC_IGN_AUTO_OFF_TIMEOUT)) {
        setRelay(PIN_ACC, false);
        setRelay(PIN_IGN, false);
        ledSuppressedAfterShutdown = true;
        changeState(STATE_UNLOCKED);
        break;
      }

      if (btnJustPressed) {
        if (isKeyPresent && brakePressed && hbPulled) {
          triggerLedFeedback();
          changeState(STATE_CRANKING); // FR-16, FR-17, FR-18: תמיד 1s גם מ-IGN_ON
        } else {
          // FR-32: כיבוי — תנאי התנעה לא מתקיימים במלואם (כולל אובדן מפתח)
          triggerLedFeedback();
          setRelay(PIN_ACC, false);
          setRelay(PIN_IGN, false);
          ledSuppressedAfterShutdown = true;
          changeState(STATE_UNLOCKED);
        }
      }
      break;

    // STATE_CRANKING: רצף התנעה — FR-17, FR-18, FR-19
    case STATE_CRANKING:
      {
        // FR-17, FR-18: תמיד 1s לפני START — לא משנה מאיפה הגענו
        if (millis() - stateEnterTime < PRE_START_DELAY) {
          // שלב 1: ACC + IGN, ממתינים לייצוב ולחץ דלק
          setRelay(PIN_ACC,   true);
          setRelay(PIN_IGN,   true);
          setRelay(PIN_START, false);
        } else if (millis() - stateEnterTime < (PRE_START_DELAY + START_PULSE)) {
          // שלב 2: ניתוק ACC, הפעלת סטרטר — FR-19
          setRelay(PIN_ACC,   false);
          setRelay(PIN_IGN,   true);
          setRelay(PIN_START, true);
        } else {
          // שלב 3: סיום התנעה, החזרת ACC
          setRelay(PIN_START, false);
          setRelay(PIN_ACC,   true);
          changeState(STATE_ENGINE_RUNNING);
          break;
        }
        // תרחיש 15: שחרור ברקס באמצע התנעה = עצירת סטרטר מיידית
        if (!brakePressed) {
          setRelay(PIN_START, false);
          changeState(STATE_IGN_ON);
          break;
        }
      }
      break;

    // STATE_ENGINE_RUNNING: מנוע פועל — FR-21, SR-06
    case STATE_ENGINE_RUNNING:
      setRelay(PIN_ACC,   true);
      setRelay(PIN_IGN,   true);
      setRelay(PIN_START, false);

      // SR-06: אובדן מפתח לא מכבה מנוע

      if (btnPressed) {
        if (btnPressStartTime == 0) btnPressStartTime = millis();
        // FR-33: כיבוי חירום — לחיצה רצופה 5 שניות, ללא תנאי ברקס/HB
        if (millis() - btnPressStartTime >= EMERGENCY_STOP_PRESS) {
          setRelay(PIN_ACC,   false);
          setRelay(PIN_IGN,   false);
          ledSuppressedAfterShutdown = true;
          btnPressStartTime = 0;
          changeState(STATE_UNLOCKED);
          break;
        }
      } else {
        if (btnPressStartTime > 0) {
          unsigned long pressDuration = millis() - btnPressStartTime;
          // FR-31: כיבוי רגיל — דורש ברקס + בלם יד
          // FR-34, SR-05: תנאי כיבוי לא מתקיימים = התעלמות מוחלטת
          if (pressDuration < EMERGENCY_STOP_PRESS && brakePressed && hbPulled) {
            setRelay(PIN_ACC,   false);
            setRelay(PIN_IGN,   false);
            ledSuppressedAfterShutdown = true;
            changeState(STATE_UNLOCKED);
            btnPressStartTime = 0;
            break;
          }
          btnPressStartTime = 0;
        }
      }
      break;
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
